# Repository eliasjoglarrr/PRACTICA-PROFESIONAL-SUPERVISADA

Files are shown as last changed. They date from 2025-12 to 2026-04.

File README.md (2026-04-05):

<p align="center">
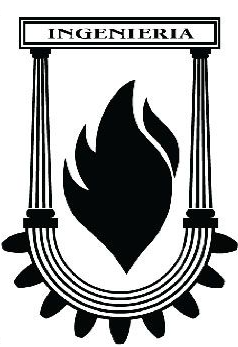
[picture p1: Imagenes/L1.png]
Imagen izquierda
  
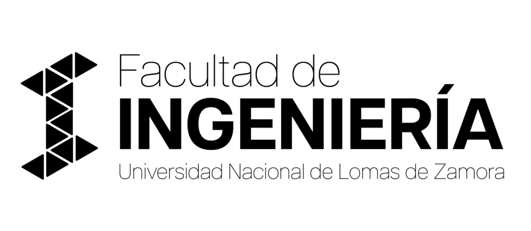
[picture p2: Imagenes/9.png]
  
  Imagen derecha
</p>

# Sistema de Manipulación Automatizada para Brazo Robot

Este repositorio contiene el diseño y documentación de un **sistema modular de manipulación automatizada**, desarrollado en el marco de la **Práctica Profesional Supervisada** de la carrera **Ingeniería Mecatrónica** (UNLZ).

El sistema está pensado para ser utilizado por un **brazo robótico**, permitiendo la sujeción, posicionamiento, almacenamiento y dispensado de piezas de manera **repetible, segura y flexible**.

---

## Descripción del Proyecto

<p align="center">
  Proceso de automatización
</p>

El proyecto consiste en el diseño de un conjunto modular compuesto por:

- **Bandeja principal con agarre en forma de H**, diseñada para acoplarse al TCP del robot.
- **Tres piezas intercambiables**:
  - Dos piezas espejadas (derecha e izquierda).
  - Una pieza de mayor longitud.
- **Dispensador por gravedad**, encargado de almacenar y suministrar las piezas al área de pick-up del robot.

Todo el sistema fue desarrollado en **CAD 3D**, priorizando la modularidad, la repetitibilidad en la manipulación robótica y la facilidad de mantenimiento.

---

## Objetivo General

Diseñar y validar un sistema modular de manipulación compuesto por una bandeja con agarre en H, piezas intercambiables y un dispensador, que permita la sujeción, alimentación y manipulación confiable por un brazo robot mediante TCP.

---

## Componentes del Sistema

### 1. Bandeja con agarre en H
- Base de posicionamiento impresa en 3D.
- Orificios hembra para el encastre preciso de las piezas.
- Estructura superior en forma de **H**, optimizada para el agarre del gripper.
- Diseño dividido en dos partes para facilitar el reemplazo ante roturas.

- <p align="center">
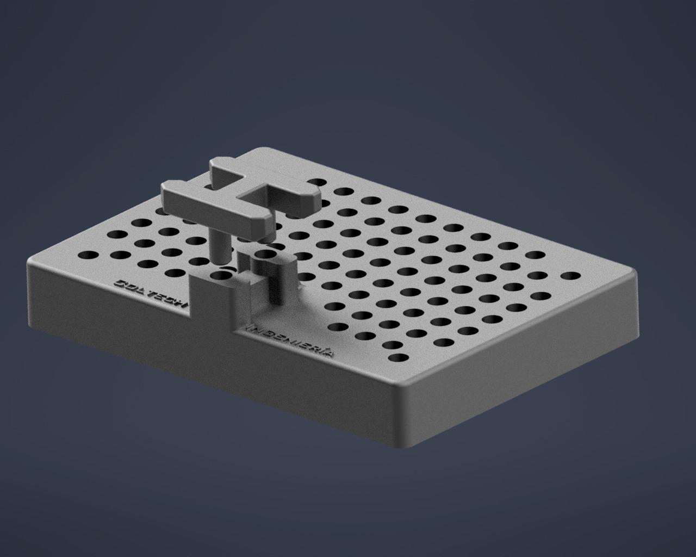
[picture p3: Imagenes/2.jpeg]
  
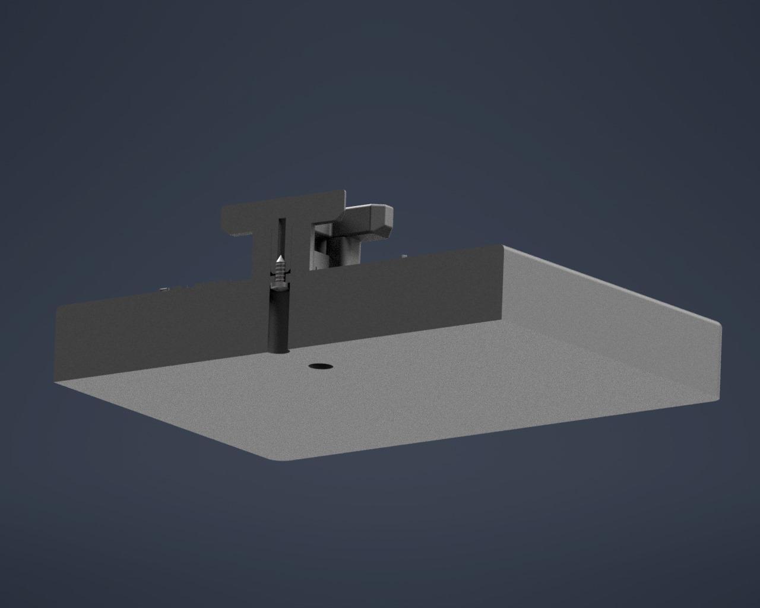
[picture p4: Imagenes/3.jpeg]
  
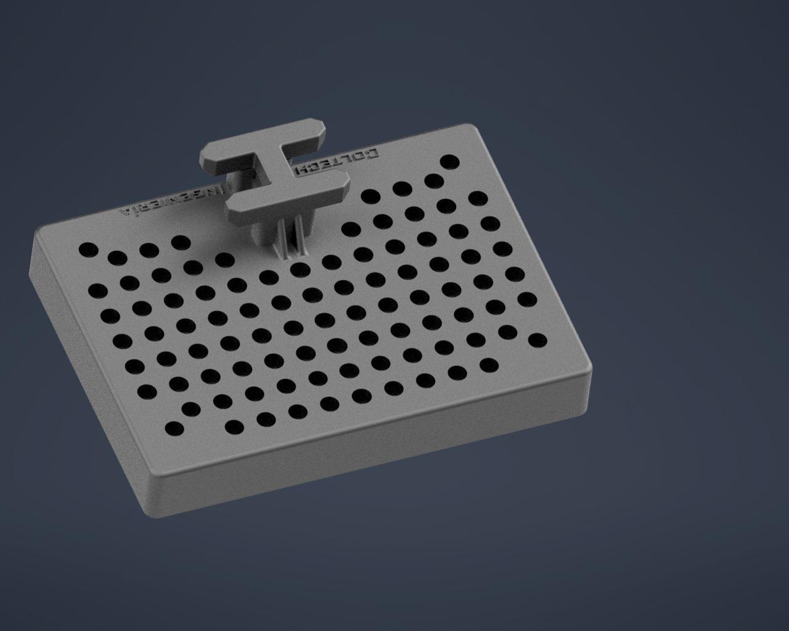
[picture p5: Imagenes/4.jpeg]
  
</p>

### 2. Piezas intercambiables
- Piezas impresas en 3D.
- Encastres tipo macho para posicionamiento preciso.
- Ranuras laterales para el agarre del TCP.
- Orificio superior para el ingreso de esferas de acero.
- Encastres superiores que permiten modularidad y acople con otras piezas.

### 3. Dispensador por gravedad
- Fabricado en chapa galvanizada plegada.
- Longitud aproximada: 400 mm.
- Inclinación cercana a 45°.
- Alimentación de piezas sin motores ni actuadores.
- Holgura aproximada de 1 mm para evitar trabas.
- Tope final que define la posición exacta de pick-up.
- Diseño que permite el ingreso del gripper sin interferencias.

- <p align="center">
  Proceso de automatización
- <p align="center">
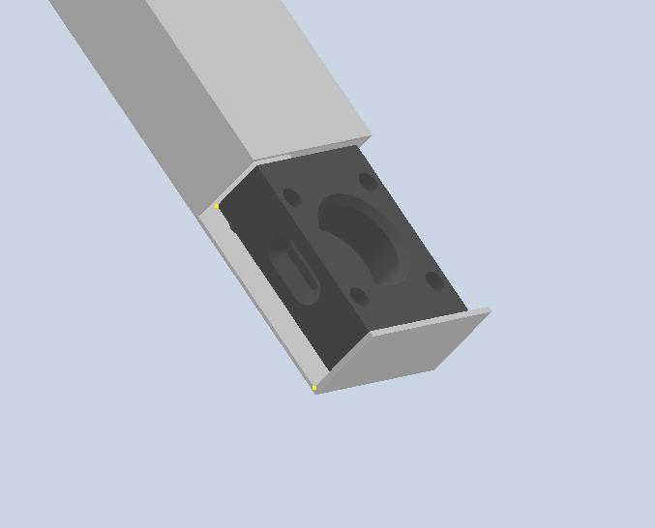
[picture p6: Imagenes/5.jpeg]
  
</p>
---

## Tecnologías y Herramientas

- **Diseño CAD 3D**
- **Impresión 3D** (para bandeja y piezas)
- **Chapa galvanizada plegada** (dispensador)
- Exportación de archivos en formatos **STEP / IGES**

---

## Validación y Pruebas

- Verificación de tolerancias y encastres.
- Pruebas de repetitibilidad en la manipulación.
- Evaluación de estabilidad durante el agarre y traslado.
- Pruebas funcionales del dispensador por gravedad.

---

## Alcance del Proyecto

Este repositorio cubre:
- Diseño y desarrollo del sistema.
- Modelos 3D de todos los componentes.
- Documentación técnica del funcionamiento.
- Base para futuras mejoras y adaptaciones a nuevas geometrías.

No incluye la programación del robot ni la integración con sistemas de control industrial.

---

## Autores

- **De Lio, Nicolás**
- **Bellomi, Federico**
- **Elías Joglar**

Carrera: Ingeniería Mecatrónica  
Facultad de Ingeniería – Universidad Nacional de Lomas de Zamora

---

## Tutores

- Tutor Institucional: Martín González  
- Tutor Académico: Cristian Lukaszewicz

---

## Licencia

Este proyecto se desarrolló con fines académicos.  

---

## 📷 Imágenes y Modelos

Las imágenes, renders y archivos CAD del sistema se encuentran disponibles en el repositorio.

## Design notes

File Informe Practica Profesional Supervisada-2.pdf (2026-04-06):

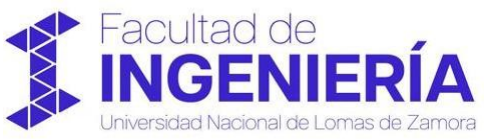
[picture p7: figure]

### PRACTICA PROFESIONAL SUPERVISADA

Alumnos/DNI

De lio Nicolás 44107398

Bellomi Federico 42.598.287

Elias Joglar 44253292

Carrera: Ingeniería Mecatrónica

Tutor Institucional: Martin Gonzalez

Tutor Académico: Cristian Lukaszewicz

### Facultad de Ingeniería

Informe de Practica Profesional Supervisada – UNLZ

## Contenido

Evaluación

Firma del Tutor: |
Aclaración: |
Fecha: |

### 1. Observaciones Generales

Presentación

Introducción

En el presente informe se documenta el proceso de diseño y desarrollo de un conjunto modular destinado a la manipulación automatizada por un brazo robot. El sistema principal consiste en una pieza tipo "bandeja" diseñada en 3D, con orificios para la inserción y sujeción de piezas complementarias, y un agarre en forma de H pensado para acoplarse al TCP de un manipulador robótico. El objetivo central fue crear una interfaz geométrica fiable y repetible que permita al robot tomar, trasladar y liberar las piezas con precisión y seguridad.

Adicionalmente, se diseñaron tres elementos intercambiables que encajan en la bandeja: dos piezas con la misma forma, pero en versión derecha e izquierda, y una tercera pieza de mayor longitud. Estas variantes responden a la necesidad de disponer de diferentes tipos de piezas dentro de un mismo portador, facilitando la flexibilidad del sistema y reduciendo tiempos de cambio de utillaje. Para completar la solución, se desarrolló un dispensador capaz de alojar y suministrar cada uno de los tres tipos de piezas, integrando la logística de alimentación con la operación del robot.

Durante el diseño se priorizaron criterios de encaje y tolerancias para asegurar un ajuste seguro entre bandeja y piezas, además de considerar la geometría del agarre en H para que el TCP del robot garantice un acoplamiento estable durante las maniobras. Asimismo, se prestó atención a la modularidad y facilidad de montaje/desmontaje, con el fin de simplificar el mantenimiento y posibilitar futuras modificaciones o adaptaciones a otros tipos de piezas.

Objetivo general

Diseñar y validar un sistema modular de manipulación compuesto por una bandeja con agarre en H, tres piezas intercambiables y un dispensador, para permitir la sujeción, alimentación y manipulación fiable por un brazo robot mediante TCP.

Objetivos específicos

1. Generar modelos CAD 3D completos de la bandeja, las tres piezas intercambiables y el dispensador, con geometrías parametrizadas que faciliten modificaciones.
Archivos CAD exportables (STEP/IGES)
2. Definir tolerancias y ajustes funcionales entre bandeja y piezas para asegurar encaje seguro y repetible durante la manipulación robótica.
3. Diseñar el agarre en forma de H optimizado para el TCP del robot (dimensiones, puntos de contacto y holguras) que garantice estabilidad en traslado y giro.

4. Desarrollar el dispensador que albergue y entregue cada tipo de pieza al área de pick-up, contemplando mecanismos de retención y liberación.
5. Verificar la modularidad y facilidad de montaje/desmontaje para mantenimiento y cambios de utillaje mediante ensambles
6. Realizar un plan de pruebas funcionales para validar la sujeción, inserción, dispensado y manipulación por robot (pruebas dimensionales y de repetibilidad).
7. Proponer materiales y procesos de fabricación adecuados para las piezas (considerando rigidez, desgaste y coste)

Alcance

El alcance de este proyecto abarca el diseño, desarrollo y validación de un sistema de manipulación automatizada que incluye una bandeja modular con tres piezas intercambiables y un dispensador, enfocado en su interacción con un brazo robot. Este sistema tiene como objetivo optimizar el proceso de sujeción,
almacenamiento y entrega de piezas en un entorno automatizado, garantizando la eficiencia y la repetibilidad en las operaciones.

Componentes incluidos en el alcance:

1. Bandeja con agarre en H:
- Diseño de una bandeja modular con agujeros específicos para insertar las tres piezas intercambiables.
- Creación de un sistema de agarre en forma de H para asegurar una conexión estable con el TCP del brazo robot.
2. Piezas intercambiables:
- Diseño de tres piezas que se insertan en la bandeja.
3. Dispensador:
- Diseño de un dispensador que permita almacenar y liberar las tres piezas intercambiables de forma eficiente.
- Desarrollo de un mecanismo para asegurar que las piezas sean entregadas de forma precisa y segura al área de trabajo del brazo robot.
4. Validación y pruebas:
- Realización de pruebas para asegurar la funcionalidad del sistema, incluyendo la verificación del encaje entre las piezas, el mecanismo de sujeción, y la operación del dispensador.
- Pruebas de manipulación automatizada con un brazo robot, evaluando la repetibilidad y estabilidad en la toma y colocación de las piezas.

Resumen

En este trabajo se desarrolló el diseño de un sistema modular orientado a la manipulación automatizada mediante un brazo robot. El conjunto está compuesto por una bandeja principal con un sistema de agarre en forma de H, tres piezas intercambiables que se incrustan en dicha bandeja y un dispensador destinado al almacenamiento y suministro de estas piezas. El diseño fue realizado íntegramente en entorno CAD 3D, priorizando la compatibilidad geométrica, la modularidad y la repetibilidad en la manipulación robótica.

La bandeja fue concebida como el elemento central del sistema, incorporando alojamientos específicos para la inserción de las piezas y un agarre optimizado para su toma por el TCP del robot. Las piezas intercambiables incluyen dos variantes espejadas (derecha e izquierda) y una tercera de mayor longitud, permitiendo cubrir distintas configuraciones sin necesidad de cambiar el elemento de manipulación principal. Por su parte, el dispensador fue diseñado para organizar y entregar de forma controlada cada uno de los tipos de piezas, facilitando su integración.

Durante el desarrollo se tuvieron en cuenta aspectos como tolerancias de encaje, facilidad de montaje y desmontaje, y la estabilidad durante la manipulación.

En conclusión, el proyecto presenta una solución de diseño flexible y escalable que sienta las bases para la automatización del manejo de piezas, mejorando la repetibilidad del proceso, al tiempo que permite futuras adaptaciones a nuevas geometrías o requerimientos.

Dispensador por gravedad

El dispositivo realizado consiste en un dispensador por gravedad fabricado con chapa galvanizada plegada, de aproximadamente 400 mm de largo, cuyo objetivo es alimentar piezas impresas en 3D asegurando que siempre queden en la misma posición para que el robot pueda tomarlas. El sistema se coloca con una inclinación cercana a los 45°, lo que permite que las piezas se deslicen por su propio peso a lo largo del canal, sin necesidad de utilizar motores u otros actuadores. El canal fue diseñado dejando una holgura aproximada de 1 mm entre la pieza y la chapa, con el fin de evitar que la pieza se trabe durante el recorrido, pero manteniendo igualmente su orientación. Al final del dispensador se dispone un tope metálico que frena la pieza y define su posición final, mientras que, gracias a los cortes laterales del diseño, los costados de la pieza quedan libres. Esto permite que la pinza correspondiente al TCP ingrese sin interferencias, sujete la pieza a través de sus ranuras laterales y la retire hacia arriba para continuar con el proceso de automatización.

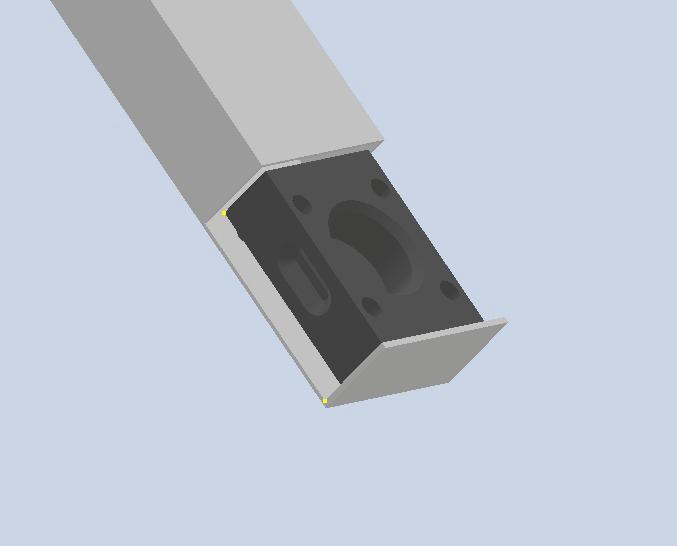
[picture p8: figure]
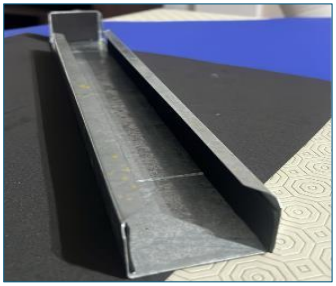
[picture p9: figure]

Piezas Modeladas en 3D

Base Principal

La pieza principal corresponde a una base de posicionamiento impresa en 3D, diseñada para lograr el centrado preciso de las piezas previo a su manipulación por el robot. La base presenta una serie de orificios (entrantes hembras) distribuidos según el mismo patrón geométrico que los salientes (machos) presentes en las piezas, lo que permite que estas se apoyen siempre en la misma posición y orientación. De esta forma se reduce el error de posicionamiento y se asegura la repetitibilidad del sistema. Además, la base cuenta con una estructura superior con forma de “H”, la cual fue diseñada específicamente para facilitar el agarre por parte del gripper del TCP, ya que la pinza utilizada posee una geometría compatible con dicha forma. A partir de pruebas realizadas durante el funcionamiento del sistema, se observó que la estructura en H era la parte que más frecuentemente se rompía durante la toma de las piezas, debido a los esfuerzos mecánicos repetitivos. Por este motivo, se decidió dividir el diseño en dos partes, separando la H del cuerpo principal de la base, de modo que, en caso de rotura, solo sea necesario reimprimir dicha pieza, evitando así desperdiciar la base completa, la cual resulta más robusta y requiere mayor tiempo y material de impresión

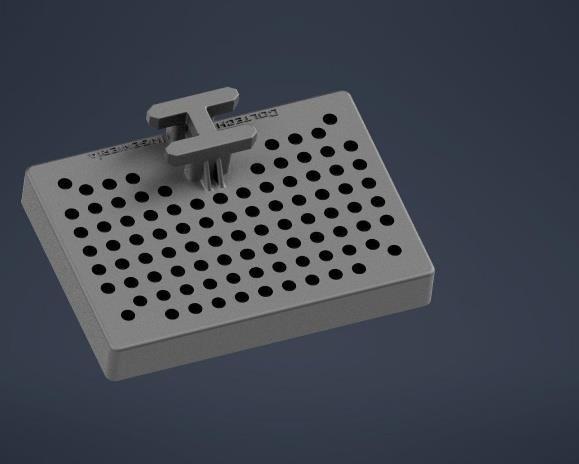
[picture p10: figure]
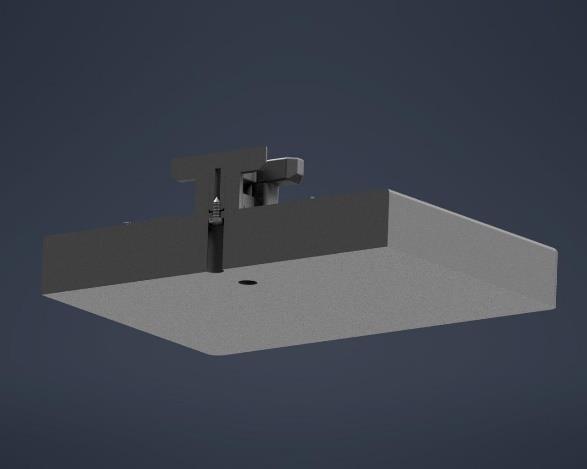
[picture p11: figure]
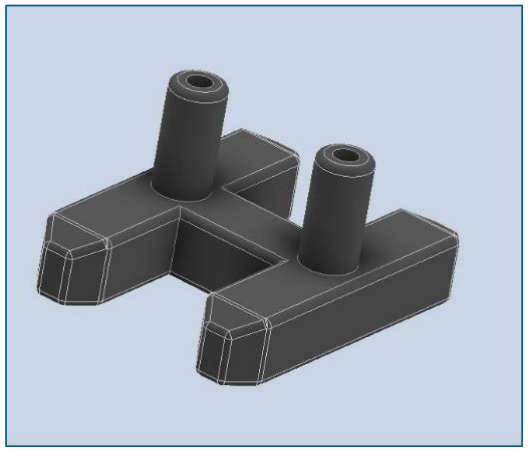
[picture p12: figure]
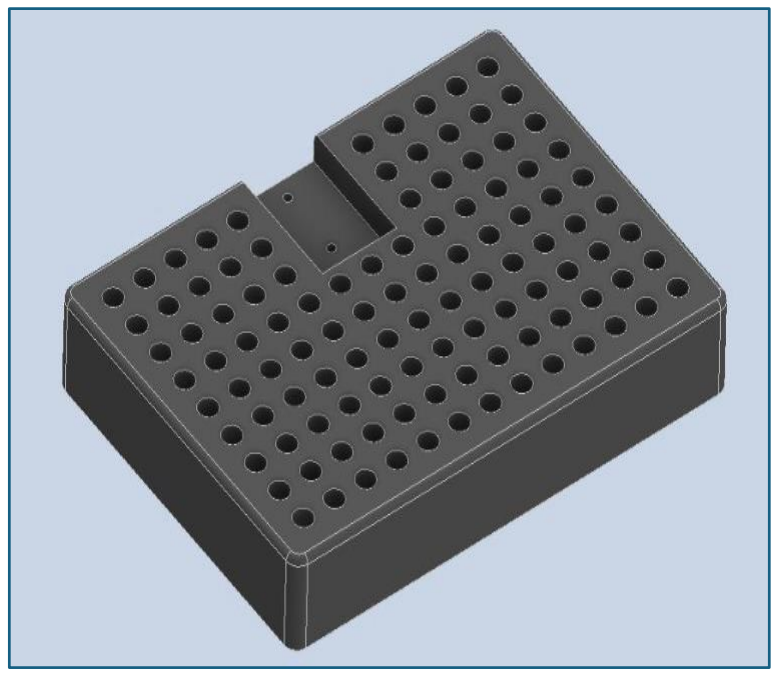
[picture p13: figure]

Piezas encastrables

Las piezas encastrables son piezas impresas en 3D diseñadas para interactuar tanto con el sistema de posicionamiento como con el robot. En la parte superior, la pieza presenta un orificio circular, el cual está destinado al ingreso de pequeñas esferas de acero, cumpliendo una función específica dentro del conjunto. En los laterales de la pieza se incorporan ranuras, cuya finalidad es permitir el agarre por parte del TCP del robot, asegurando una sujeción estable durante la manipulación. En la cara inferior se encuentran los encastres tipo macho, los cuales encajan con los orificios hembra de la base, garantizando un posicionamiento preciso y repetible. A su vez, en la parte superior de la pieza también se incorporaron encastres hembra, permitiendo el acople con otra pieza adicional, lo que otorga modularidad al diseño y facilita el armado del conjunto.

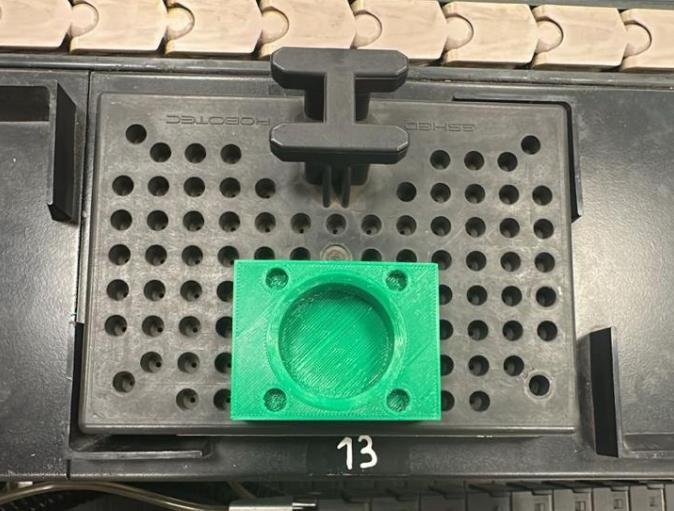
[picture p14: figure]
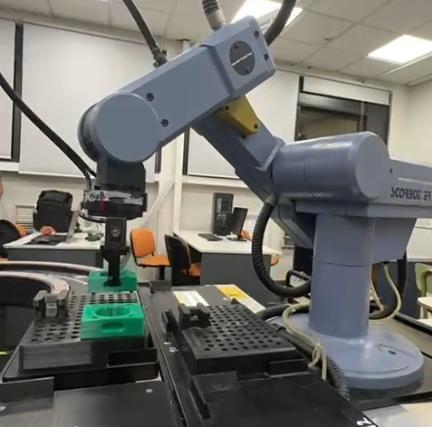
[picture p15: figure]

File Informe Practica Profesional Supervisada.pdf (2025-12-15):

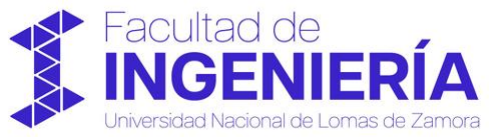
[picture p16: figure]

### PRACTICA PROFESIONAL SUPERVISADA

Alumnos/DNI

De lio Nicolás 44107398

Bellomi Federico 42.598.287

Elias Joglar 44253292

Carrera: Ingeniería Mecatrónica

Tutor Institucional: Martin Gonzalez

Tutor Académico: Cristian Lukaszewicz

Facultad de Ingeniería - Universidad Nacional de Lomas de Zamora

Informe de Practica Profesional Supervisada – UNLZ

## Contenido

Presentación

Introducción

En el presente informe se documenta el proceso de diseño y desarrollo de un conjunto modular destinado a la manipulación automatizada por un brazo robot. El sistema principal consiste en una pieza tipo "bandeja" diseñada en 3D, con orificios para la inserción y sujeción de piezas complementarias, y un agarre en forma de H pensado para acoplarse al TCP de un manipulador robótico. El objetivo central fue crear una interfaz geométrica fiable y repetible que permita al robot tomar, trasladar y liberar las piezas con precisión y seguridad.

Adicionalmente, se diseñaron tres elementos intercambiables que encajan en la bandeja: dos piezas con la misma forma, pero en versión derecha e izquierda, y una tercera pieza de mayor longitud. Estas variantes responden a la necesidad de disponer de diferentes tipos de piezas dentro de un mismo portador, facilitando la flexibilidad del sistema y reduciendo tiempos de cambio de utillaje. Para completar la solución, se desarrolló un dispensador capaz de alojar y suministrar cada uno de los tres tipos de piezas, integrando la logística de alimentación con la operación del robot.

Durante el diseño se priorizaron criterios de encaje y tolerancias para asegurar un ajuste seguro entre bandeja y piezas, además de considerar la geometría del agarre en H para que el TCP del robot garantice un acoplamiento estable durante las maniobras. Asimismo, se prestó atención a la modularidad y facilidad de montaje/desmontaje, con el fin de simplificar el mantenimiento y posibilitar futuras modificaciones o adaptaciones a otros tipos de piezas.

Objetivo general

Diseñar y validar un sistema modular de manipulación compuesto por una bandeja con agarre en H, tres piezas intercambiables y un dispensador, para permitir la sujeción, alimentación y manipulación fiable por un brazo robot mediante TCP.

Objetivos específicos

1. Generar modelos CAD 3D completos de la bandeja, las tres piezas intercambiables y el dispensador, con geometrías parametrizadas que faciliten modificaciones.
Archivos CAD exportables (STEP/IGES)
2. Definir tolerancias y ajustes funcionales entre bandeja y piezas para asegurar encaje seguro y repetible durante la manipulación robótica.
3. Diseñar el agarre en forma de H optimizado para el TCP del robot (dimensiones, puntos de contacto y holguras) que garantice estabilidad en traslado y giro.

4. Desarrollar el dispensador que albergue y entregue cada tipo de pieza al área de pick-up, contemplando mecanismos de retención y liberación.
5. Verificar la modularidad y facilidad de montaje/desmontaje para mantenimiento y cambios de utillaje mediante ensambles
6. Realizar un plan de pruebas funcionales para validar la sujeción, inserción, dispensado y manipulación por robot (pruebas dimensionales y de repetibilidad).
7. Proponer materiales y procesos de fabricación adecuados para las piezas (considerando rigidez, desgaste y coste)

Alcance

El alcance de este proyecto abarca el diseño, desarrollo y validación de un sistema de manipulación automatizada que incluye una bandeja modular con tres piezas intercambiables y un dispensador, enfocado en su interacción con un brazo robot. Este sistema tiene como objetivo optimizar el proceso de sujeción,
almacenamiento y entrega de piezas en un entorno automatizado, garantizando la eficiencia y la repetibilidad en las operaciones.

Componentes incluidos en el alcance:

1. Bandeja con agarre en H:
- Diseño de una bandeja modular con agujeros específicos para insertar las tres piezas intercambiables.
- Creación de un sistema de agarre en forma de H para asegurar una conexión estable con el TCP del brazo robot.
2. Piezas intercambiables:
- Diseño de tres piezas que se insertan en la bandeja.
3. Dispensador:
- Diseño de un dispensador que permita almacenar y liberar las tres piezas intercambiables de forma eficiente.
- Desarrollo de un mecanismo para asegurar que las piezas sean entregadas de forma precisa y segura al área de trabajo del brazo robot.
4. Validación y pruebas:
- Realización de pruebas para asegurar la funcionalidad del sistema, incluyendo la verificación del encaje entre las piezas, el mecanismo de sujeción, y la operación del dispensador.
- Pruebas de manipulación automatizada con un brazo robot, evaluando la repetibilidad y estabilidad en la toma y colocación de las piezas.

Resumen

En este trabajo se desarrolló el diseño de un sistema modular orientado a la manipulación automatizada mediante un brazo robot. El conjunto está compuesto por una bandeja principal con un sistema de agarre en forma de H, tres piezas intercambiables que se incrustan en dicha bandeja y un dispensador destinado al almacenamiento y suministro de estas piezas. El diseño fue realizado íntegramente en entorno CAD 3D, priorizando la compatibilidad geométrica, la modularidad y la repetibilidad en la manipulación robótica.

La bandeja fue concebida como el elemento central del sistema, incorporando alojamientos específicos para la inserción de las piezas y un agarre optimizado para su toma por el TCP del robot. Las piezas intercambiables incluyen dos variantes espejadas (derecha e izquierda) y una tercera de mayor longitud, permitiendo cubrir distintas configuraciones sin necesidad de cambiar el elemento de manipulación principal. Por su parte, el dispensador fue diseñado para organizar y entregar de forma controlada cada uno de los tipos de piezas, facilitando su integración.

Durante el desarrollo se tuvieron en cuenta aspectos como tolerancias de encaje, facilidad de montaje y desmontaje, y la estabilidad durante la manipulación.

En conclusión, el proyecto presenta una solución de diseño flexible y escalable que sienta las bases para la automatización del manejo de piezas, mejorando la repetibilidad del proceso, al tiempo que permite futuras adaptaciones a nuevas geometrías o requerimientos.

Dispensador por gravedad

El dispositivo realizado consiste en un dispensador por gravedad fabricado con chapa galvanizada plegada, de aproximadamente 400 mm de largo, cuyo objetivo es alimentar piezas impresas en 3D asegurando que siempre queden en la misma posición para que el robot pueda tomarlas. El sistema se coloca con una inclinación cercana a los 45°, lo que permite que las piezas se deslicen por su propio peso a lo largo del canal, sin necesidad de utilizar motores u otros actuadores. El canal fue diseñado dejando una holgura aproximada de 1 mm entre la pieza y la chapa, con el fin de evitar que la pieza se trabe durante el recorrido, pero manteniendo igualmente su orientación. Al final del dispensador se dispone un tope metálico que frena la pieza y define su posición final, mientras que, gracias a los cortes laterales del diseño, los costados de la pieza quedan libres. Esto permite que la pinza correspondiente al TCP ingrese sin interferencias, sujete la pieza a través de sus ranuras laterales y la retire hacia arriba para continuar con el proceso de automatización.

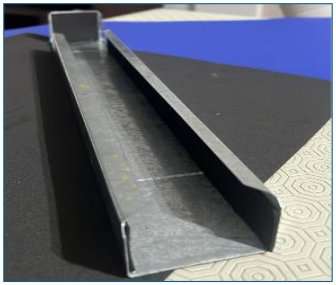
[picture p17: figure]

Piezas Modeladas en 3D

Base Principal

La pieza principal corresponde a una base de posicionamiento impresa en 3D, diseñada para lograr el centrado preciso de las piezas previo a su manipulación por el robot. La base presenta una serie de orificios (entrantes hembras) distribuidos según el mismo patrón geométrico que los salientes (machos) presentes en las piezas, lo que permite que estas se apoyen siempre en la misma posición y orientación. De esta forma se reduce el error de posicionamiento y se asegura la repetitibilidad del sistema. Además, la base cuenta con una estructura superior con forma de “H”, la cual fue diseñada específicamente para facilitar el agarre por parte del gripper del TCP, ya que la pinza utilizada posee una geometría compatible con dicha forma. A partir de pruebas realizadas durante el funcionamiento del sistema, se observó que la estructura en H era la parte que más frecuentemente se rompía durante la toma de las piezas, debido a los esfuerzos mecánicos repetitivos. Por este motivo, se decidió dividir el diseño en dos partes, separando la H del cuerpo principal de la base, de modo que, en caso de rotura, solo sea necesario reimprimir dicha pieza, evitando así desperdiciar la base completa, la cual resulta más robusta y requiere mayor tiempo y material de impresión

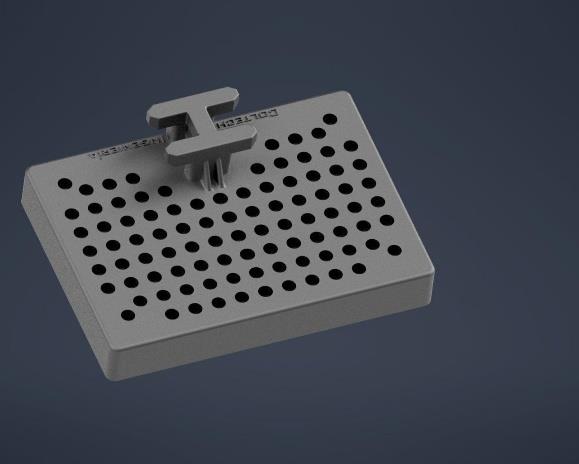
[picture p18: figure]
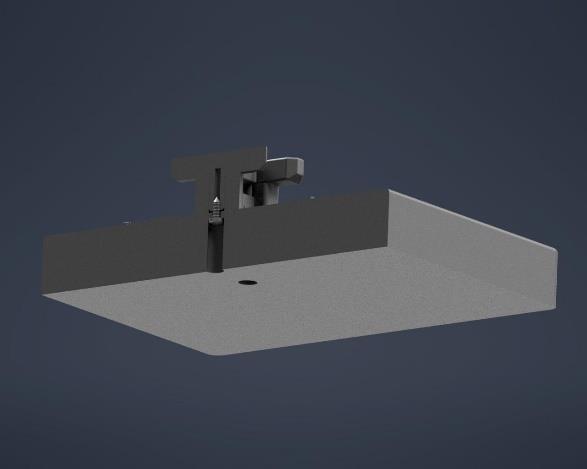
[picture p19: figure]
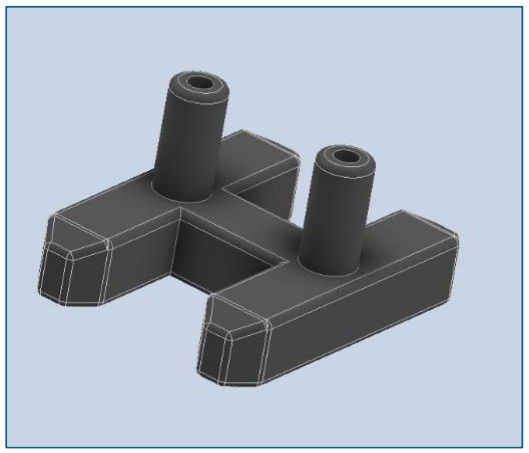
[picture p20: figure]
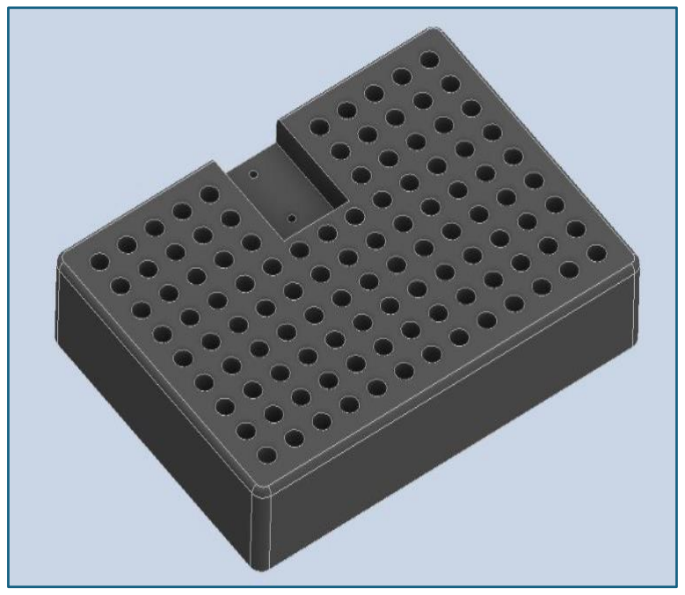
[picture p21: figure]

Piezas encastrables

Las piezas encastrables son piezas impresas en 3D diseñadas para interactuar tanto con el sistema de posicionamiento como con el robot. En la parte superior, la pieza presenta un orificio circular, el cual está destinado al ingreso de pequeñas esferas de acero, cumpliendo una función específica dentro del conjunto. En los laterales de la pieza se incorporan ranuras, cuya finalidad es permitir el agarre por parte del TCP del robot, asegurando una sujeción estable durante la manipulación. En la cara inferior se encuentran los encastres tipo macho, los cuales encajan con los orificios hembra de la base, garantizando un posicionamiento preciso y repetible. A su vez, en la parte superior de la pieza también se incorporaron encastres hembra, permitiendo el acople con otra pieza adicional, lo que otorga modularidad al diseño y facilita el armado del conjunto.

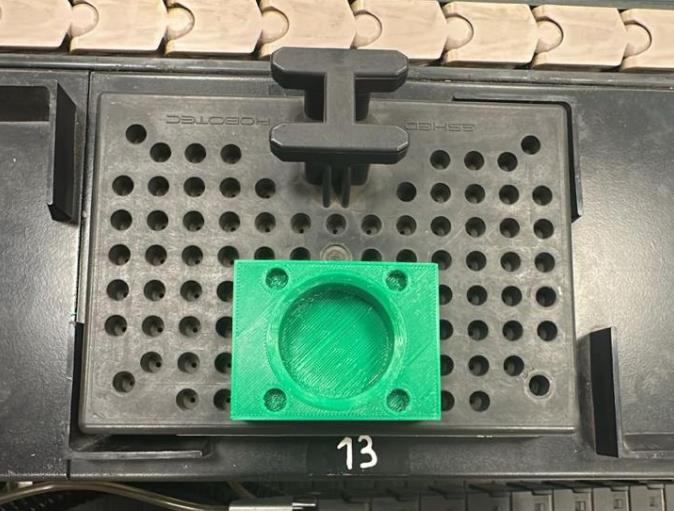
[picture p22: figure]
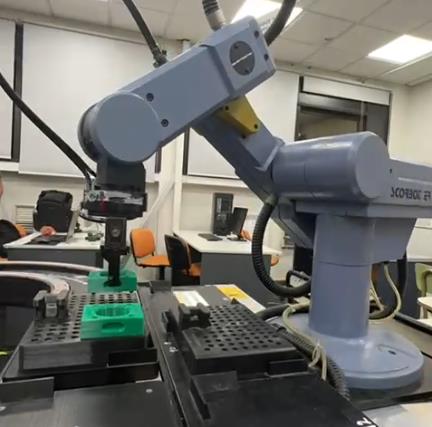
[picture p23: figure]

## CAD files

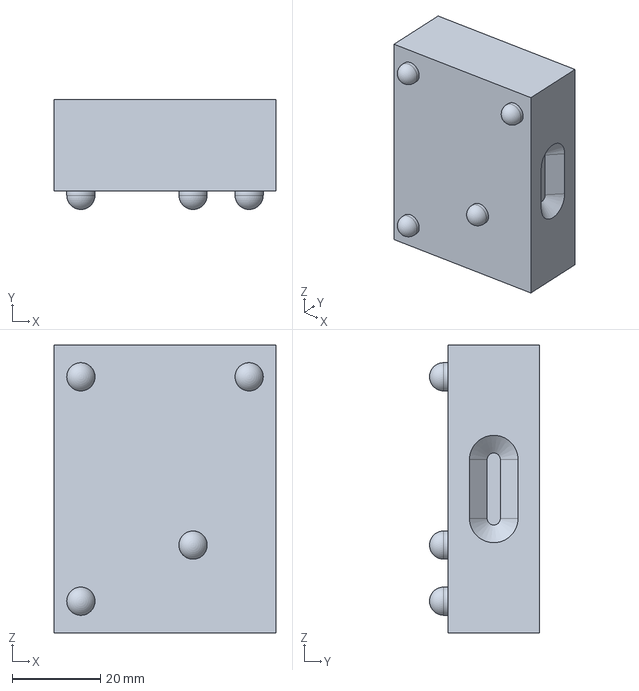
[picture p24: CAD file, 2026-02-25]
Archivos para imprimir/Pieza Izquierda.stp
50.2 x 24.9 x 65.2 mm

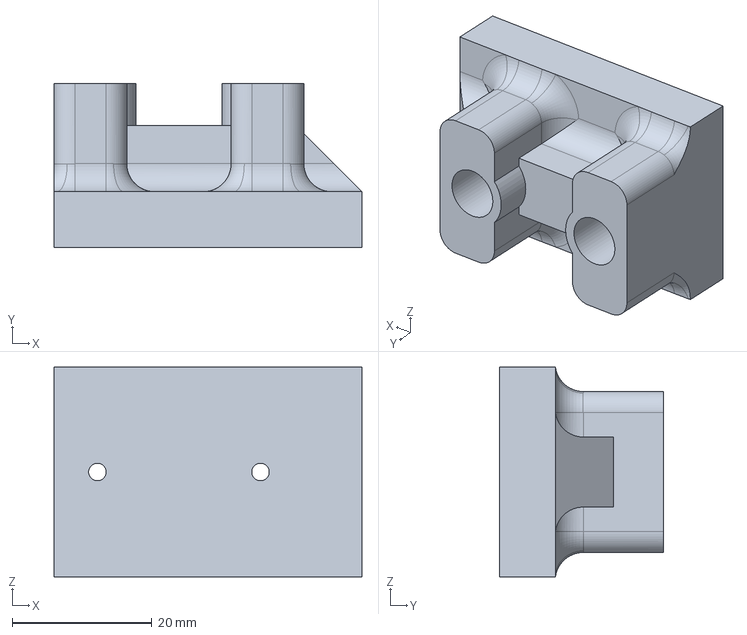
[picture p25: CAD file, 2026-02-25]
Archivos para imprimir/Primer Acople.stp
44.0 x 23.5 x 30.0 mm

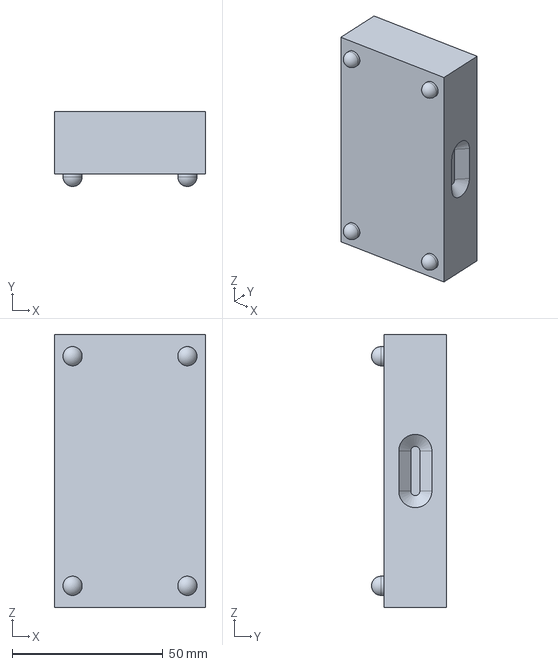
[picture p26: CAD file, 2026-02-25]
Archivos para imprimir/Pieza Central.stp
50.2 x 24.9 x 90.6 mm

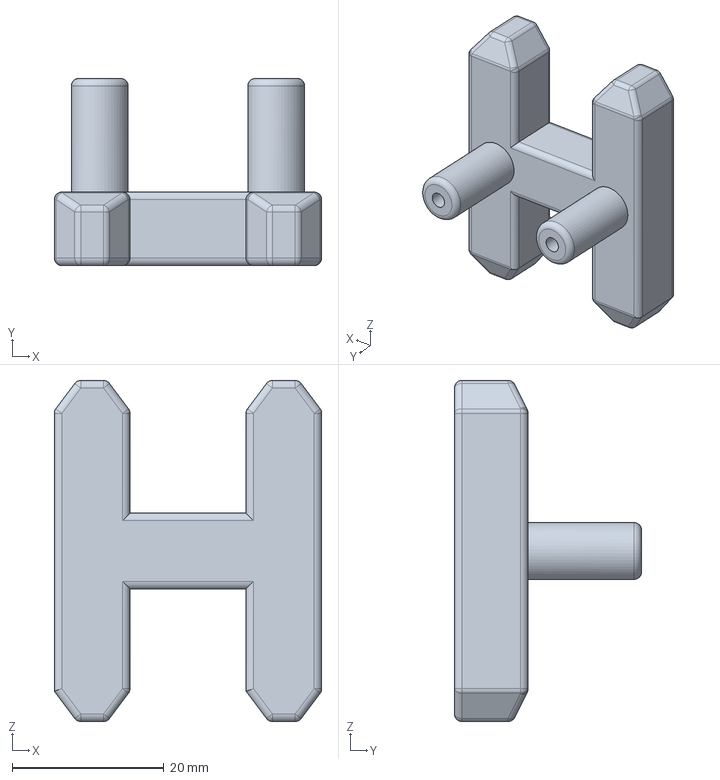
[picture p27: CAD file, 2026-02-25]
Archivos para imprimir/Segundo Acople.stp
35.3 x 24.7 x 45.0 mm

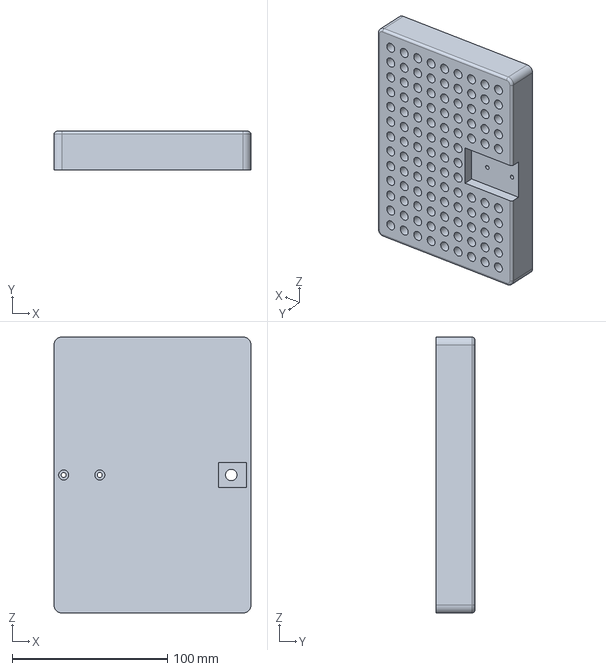
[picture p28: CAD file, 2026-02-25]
Archivos para imprimir/Base.stp
127.0 x 25.0 x 178.0 mm

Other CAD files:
Archivos para imprimir/Pieza Derecha.stp
Archivos para imprimir/Base.stl
Archivos para imprimir/Pieza Central.stl
Archivos para imprimir/Pieza Derecha.stl
Archivos para imprimir/Pieza Izquierda.stl
Archivos para imprimir/Primer Acople.stl
Archivos para imprimir/Segundo Acople.stl
OldVersions/Base.0009.ipt
OldVersions/Ensamblaje - Base con Acoples.0002.iam
OldVersions/Pieza Central.0004.ipt
OldVersions/Pieza Derecha.0005.ipt
OldVersions/Pieza Izquierda.0005.ipt
OldVersions/Pieza1.0002.ipt
OldVersions/Pieza2.0002.ipt
OldVersions/Primer Acople - reparacion.0004.ipt
OldVersions/Primer Acople.0003.ipt
OldVersions/Primer inserto.0001.ipt
OldVersions/Segundo Acople - reparacion.0005.ipt
OldVersions/Segundo Acople.0004.ipt
OldVersions/Segundo Inserto.0002.ipt
Piezas/Acople superior/Acople superior/Acople superior.ipt
Piezas/Acople superior/boitier pince.ipt
Piezas/Base.ipt
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
